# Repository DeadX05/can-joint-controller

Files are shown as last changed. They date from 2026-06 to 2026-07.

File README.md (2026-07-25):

# Distributed Joint Controller over CAN

Two-node ESP32 + CAN-bus system implementing **closed-loop PID position
control of a robotic joint** — a building block toward a quadruped leg.
A target angle typed into the supervisor crosses the bus, the joint
controller drives to it, and status frames stream back.

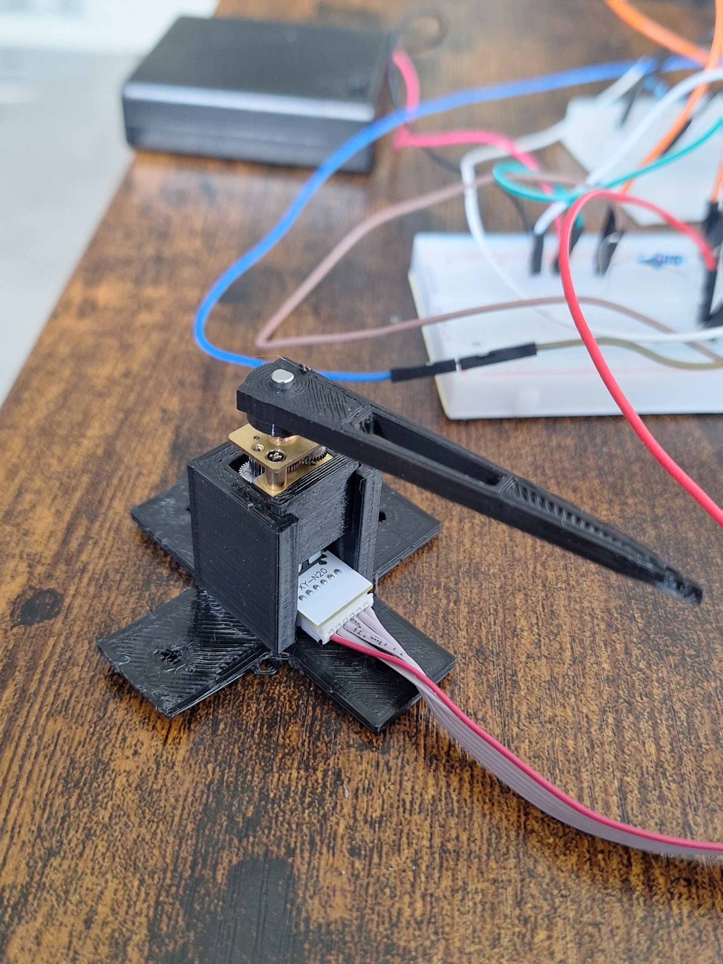
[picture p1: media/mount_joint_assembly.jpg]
Joint assembly


*Joint assembly: N20 gearmotor in the printed mount, front retaining plate
fitted, D-bore lever keyed to the output shaft.*

**[▶ Demo video](media/demo_joint_step_response.mp4)** — a
`0 → 45 → 90 → 0 → −45` step sequence.

**Status: working end to end.** Steady-state error is **0.0–0.5° across
−45°…180°, within the 0.6° control deadband.** The deadband bounds the
error by construction — the controller stops correcting once inside it, and
tightening it reintroduces the stiction limit cycle found during tuning. So
that figure is a design tradeoff, not a performance ceiling.

---

## System overview

- **Node A — joint controller.** ESP32 + TB6612 H-bridge + N20 gearmotor
  with a quadrature encoder. Runs a 100 Hz PID position loop, receives
  `0x100` position commands, publishes `0x110` status at 10 Hz.
- **Node B — supervisor.** ESP32 + MCP2551. Issues targets from serial
  input, consumes telemetry, and doubles as a CSV logging endpoint.
- **Bus.** 250 kbit/s, ESP32 TWAI driver, MCP2551 transceivers.

```
   [ Serial ]                         CAN bus, 250 kbit/s
   PC / user                       (0x100 cmd  →  0x110 status)
       │                        ┌──────────────┬──────────────┐
       ▼                        │              │              │
   ┌─────────┐   0x100 cmd   ┌──┴───┐      ┌───┴────┐    TB6612 → N20 motor
   │ Node B  │ ────────────► │ CAN  │ ◄──► │ Node A │ ──────────────► ))) joint
   │ super-  │ ◄──────────── │ wire │      │ joint  │ ◄── quadrature encoder
   │ visor   │   0x110 status└──────┘      └────────┘
   └─────────┘
```

## Repository structure

```
firmware/
  node_a_joint_controller/   PID position loop + CAN
  node_b_supervisor/         command entry, status display, CSV logging
  tools/                     CAN bring-up sketches + physical-layer self-test
docs/
  protocol.md                CAN message spec (as implemented)
  hardware.md                pinout, physical layer, termination
  engineering-log.md         CAN fault-isolation writeup  ← start here
cad/                         parametric mount/lever generators + STLs
analysis/                    step-response characterisation, plots, logger
media/                       demo video, wiring photos
```

## Hardware

ESP32 ×2, TB6612FNG driver, N20 gearmotor + quadrature encoder, MCP2551 ×2.
Transceivers run at **5 V** with a **220 Ω / 440 Ω divider on each RX line**
back down to ~3.3 V; ~110 Ω termination per node. Full pinout and the
physical-layer reasoning are in [`docs/hardware.md`](docs/hardware.md).

## CAN protocol

| ID | Direction | Payload |
|----|---|---|
| `0x100` | supervisor → joint | `int16` target, 0.1° units |
| `0x110` | joint → supervisor | pos / target / err `int16` (0.1°), effort `uint8`, flags `uint8` (bit0 = settled) |

Full spec: [`docs/protocol.md`](docs/protocol.md).

## Control

100 Hz PID: **Kp = 10, Ki = 0.1, Kd = 0.1**, with a 35-PWM stiction
breakaway, a 0.6° deadband, and an integral anti-windup clamp; range
−45°…180°. Two failure modes were found and fixed during bring-up:

1. **Direction inversion → positive-feedback runaway** — drive direction
   disagreed with the encoder's counting sense; every correction grew the
   error until PWM saturated. Fixed by swapping the H-bridge logic.
2. **Stiction limit cycle** — integral wound up against static friction and
   oscillated. Fixed with friction compensation and a tighter clamp.

## Results

Step response commanded and observed entirely over CAN, across the full
range. Steady-state error stays inside the 0.6° deadband:

| Command | Settled | Error |
|---:|---:|---:|
| 10° | 9.4–10.0° | 0.0–0.5° |
| 20° | 19.7° | 0.2° |
| 45° | 44.6–44.9° | 0.0–0.3° |
| 90° | 89.5–89.8° | 0.1–0.4° |
| 180° | 179.6–180.3° | 0.0–0.3° |
| −45° | −44.9 to −45.2° | 0.0–0.2° |

Full capture, caveats, and the 10 Hz sampling limitation:
[`analysis/step_response_over_can.md`](analysis/step_response_over_can.md).

PID tuning from Day 2 (direct serial, before the bus was integrated):

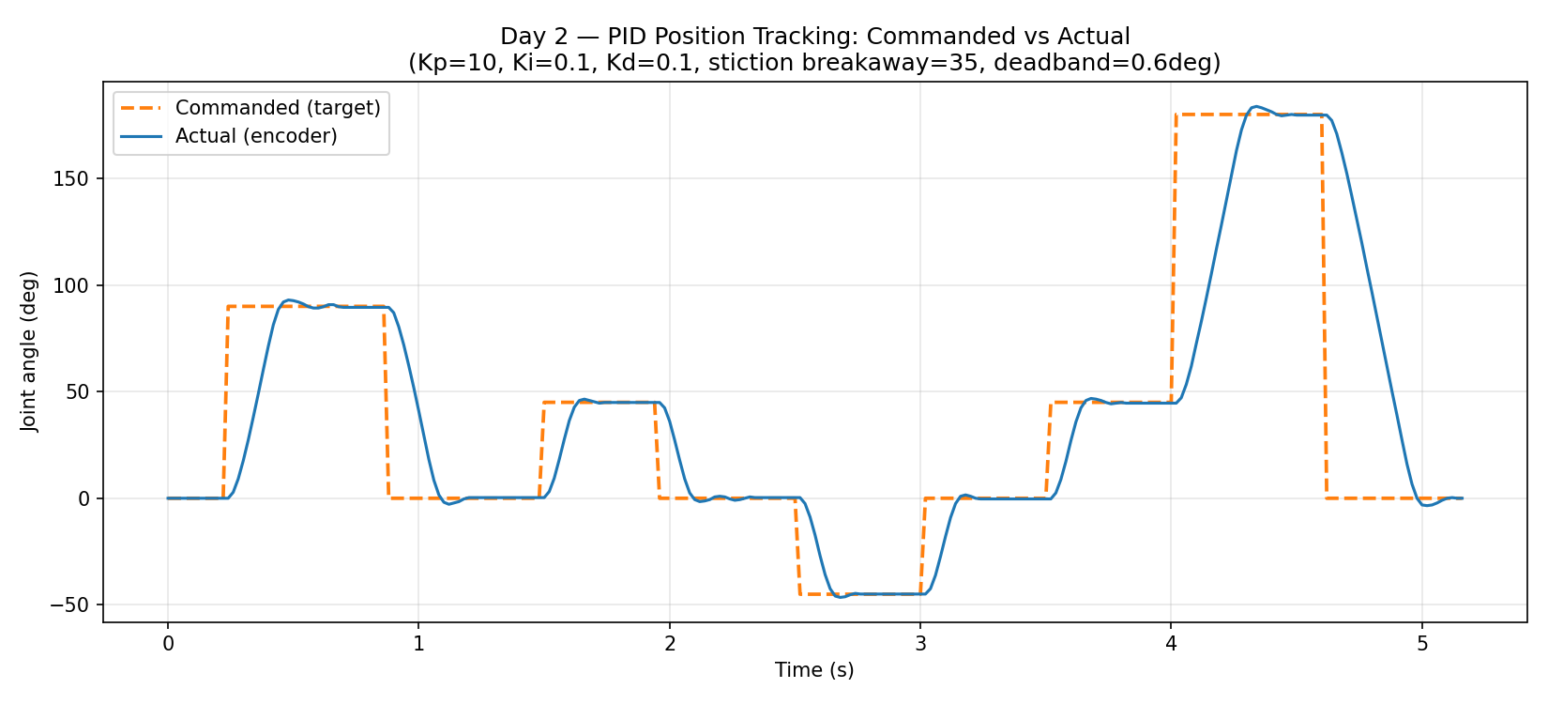
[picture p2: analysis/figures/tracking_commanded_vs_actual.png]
Commanded vs actual

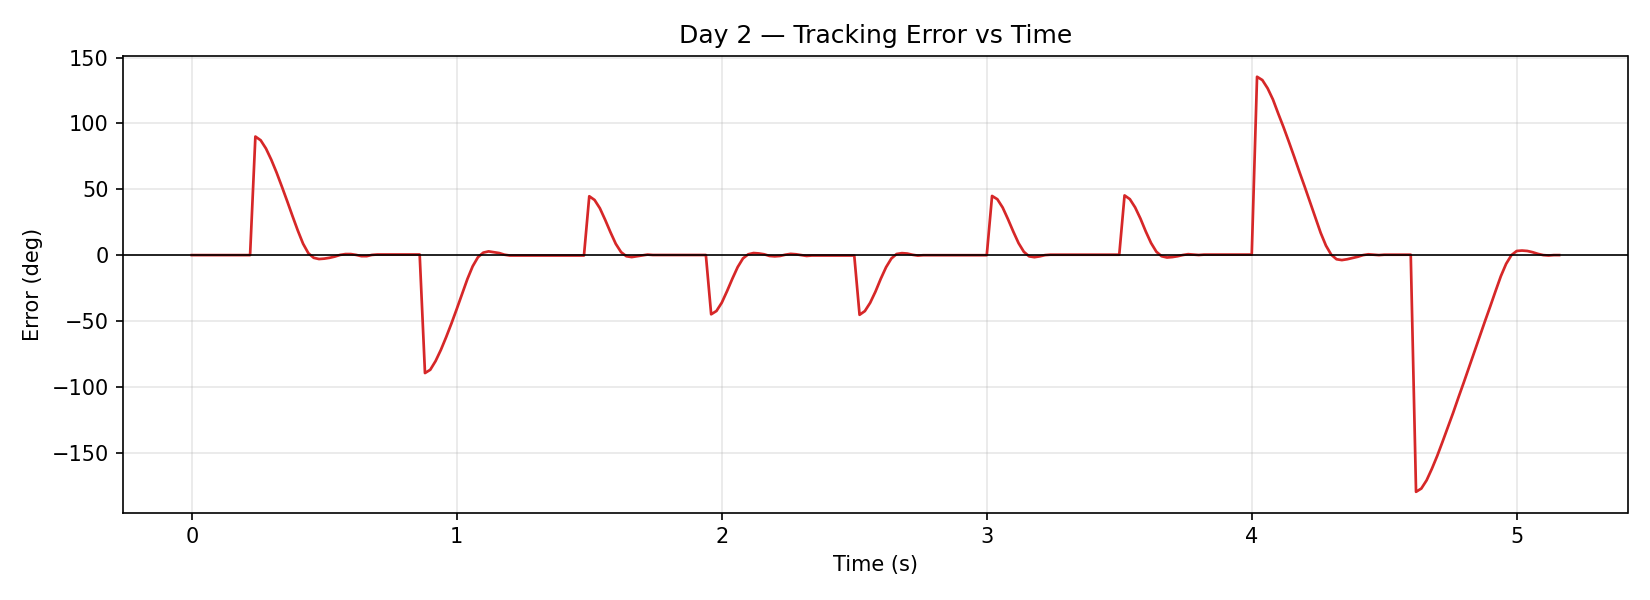
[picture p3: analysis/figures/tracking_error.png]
Tracking error


## Engineering log — the part worth reading

Physical-layer bring-up failed for days; the root cause was **three of five
hand-soldered MCP2551 modules being defective.** It was isolated with a
four-rung diagnostic ladder — status telemetry to make a silent bus
legible, a `TWAI_MODE_NO_ACK` self-test for per-node pass/fail without a
partner, GPIO loopback, and cross-swap — each rung removing one class of
suspect. Verbatim serial captures and bench measurements:
[`docs/engineering-log.md`](docs/engineering-log.md).

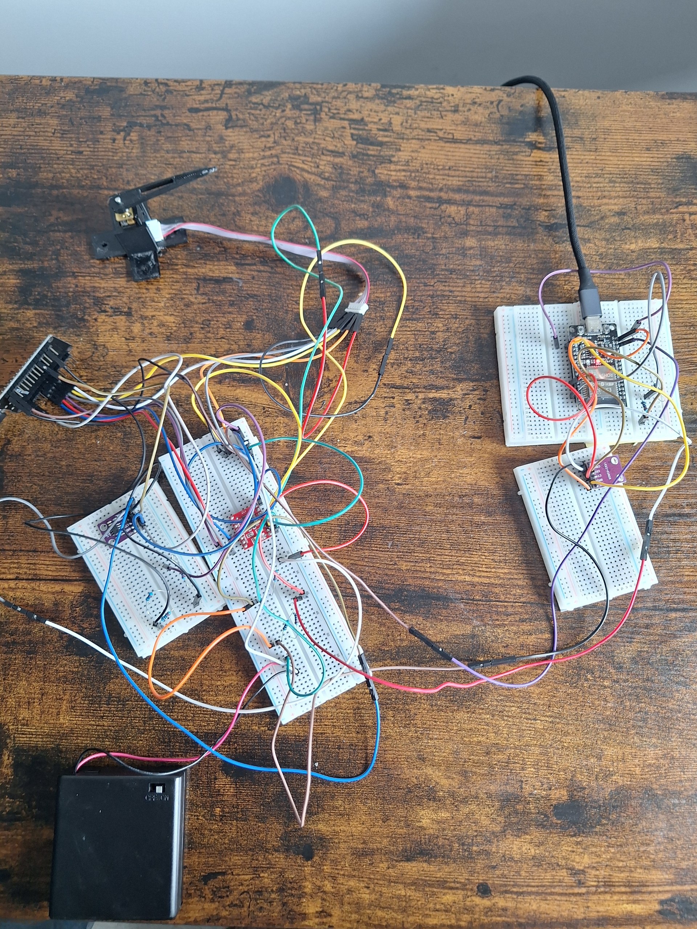
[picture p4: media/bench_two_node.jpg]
Full bench


*Full bench: joint controller node (left, with motor driver and battery)
and supervisor node (right), linked by a three-wire CAN bus.*

## Mechanical

The motor mount is parametric — original in OpenSCAD, later revisions in
Python (`trimesh`) with a named-constant block per part. The design
iterated under physical testing: closed cylindrical pocket that couldn't be
assembled → horizontal test-fit (wrong plane for the tuned PID) → vertical
shaft-up tower (**used for the working demo**) → a rejected closed-front
rev3 → the current **open-front + slide-in retaining plate** (rev4-lite).
The **D-bore lever, keyed to the motor's D-shaft, is printed and fitted**
(the first bore printed undersized in PETG and was opened up — see the
`fix(cad)` history). Generators and STLs in [`cad/`](cad/).

  ## Instructions for demo

  1. Build the hardware as shown in [`docs/hardware.md`](docs/hardware.md).
     Make sure both ESP32 grounds are connected, CANH connects to CANH, CANL
     connects to CANL, and both MCP2551 RXD lines use the documented voltage
     divider.

  2. Flash Node A with:

     `firmware/node_a_joint_controller/node_a_joint_controller.ino`

     Node A should be connected to the TB6612 motor driver, N20 motor, encoder,
     and one MCP2551 transceiver.

  3. Flash Node B with:

     `firmware/node_b_supervisor/node_b_supervisor.ino`

     Node B only needs the second MCP2551 transceiver and USB serial connection
     to the PC.

  4. Open the serial monitor for Node B at **115200 baud** with **newline**
     line ending enabled.

  5. Type target angles into the Node B serial monitor, for example:

     ```text
     45
     90
     180
     0
     -45

  Node B sends each target over CAN as a 0x100 command. Node A runs the
  PID loop and returns 0x110 status frames.

  6. To log CSV telemetry, type:

     L

     Node B will print:

     ms,pos,target,err,pwm,settled

     Type L again to stop logging. The printed rows can be saved as a CSV and
     plotted with the tools in analysis/ (analysis/).

## Known limitations

Kept deliberately visible:

- **Encoder scaling is unverified against a physical measurement.** 1146
  counts/rev was hand-calibrated and the firmware uses it, but no protractor
  check against a commanded angle was done. All reported angles are
  encoder-derived; **absolute angular accuracy is unconfirmed.**
- **Overshoot on fast steps.** Large moves travel past target and recover:
  89.5°→0 reached −1.5°, 180°→0 reached +1.2°, 0°→−45° reached −47.4° and
  −46.1° on two runs — every recovery at `pwm=35`, the stiction floor. Cause:
  the printed lever's rotational inertia back-driving the joint, with nothing
  damping it because the TB6612 is left in coast (both inputs LOW) rather
  than short brake at zero command. *Roadmap: brake instead of coast on stop.*
- **Telemetry sampling artifact.** Status frames report drive effort from
  the previous control iteration while position and error are sampled at
  send time, so the two disagree for one frame after a target change —
  visible as `err=9.9 pwm=0` in the logs. Documented in `sendStatus()`.
- **No fail-safe.** No heartbeat, command timeout, or watchdog — if the bus
  drops, the joint holds its last target forever.
- **Thin 5 V headroom.** One node's rail sits at 4.6 V (spec min 4.5 V);
  divider midpoints ~2.7 V vs a ~2.5 V threshold. A 3.3 V-native transceiver
  (SN65HVD230, TJA1051T/3) would remove the dividers and the concern.
- **Single joint; unloaded.** Multi-node bus arbitration is untested, and
  step responses carry no external load or disturbance-rejection data.

## Authors

- **Izzatbek Murodjonov ([@inteeed](https://github.com/inteeed))** —
  hardware design, physical-layer bring-up & fault isolation, PID tuning,
  mechanical design
- **Boburjon Radjapov ([@DeadX05](https://github.com/DeadX05))** — CAN
  protocol design, supervisor firmware, integration testing

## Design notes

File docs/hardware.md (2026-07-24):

# Hardware

Two-node CAN system: **Node A** (joint controller) and **Node B**
(supervisor), each an ESP32 paired with an MCP2551 CAN transceiver on a
shared 250 kbit/s bus driven by the ESP32 TWAI peripheral.

> This document reflects the **working configuration**. The CAN physical
> layer went through a 3.3 V → 5 V revision during bring-up; see
> `engineering-log.md` for that investigation.

## CAN bus / physical layer

| Signal | Connection |
|---|---|
| MCP2551 CTX (TXD) | ESP32 GPIO21 — direct (3.3 V is a valid logic high in) |
| MCP2551 CRX (RXD) | ESP32 GPIO22 — through a 220 Ω / 440 Ω divider |
| MCP2551 VCC | 5 V (ESP32 VIN) |
| MCP2551 GND | common ground |
| Bitrate | 250 kbit/s (ESP32 TWAI) |

The MCP2551 is specified for a 4.5–5.5 V supply, so the transceivers run
at **5 V**, not 3.3 V. (An earlier 3.3 V configuration was out of spec and
a suspected source of silent frame loss during bring-up — see
`engineering-log.md`.) Because RXD then swings to 5 V, each RX line uses a
**220 Ω / 440 Ω divider** stepping it down to ~3.3 V at the ESP32 input.
TXD needs nothing: 3.3 V is already a valid logic high into the
transceiver.

Measured after the migration: Node A VCC **5.0 V**, Node B VCC **4.6 V**
(in spec but little headroom), RX divider midpoints **~2.7–3.0 V** (above
the ESP32 logic-high threshold, but thin — a 3.3 V-native transceiver such
as the SN65HVD230 or TJA1051T/3 would remove both the dividers and the
headroom concern).

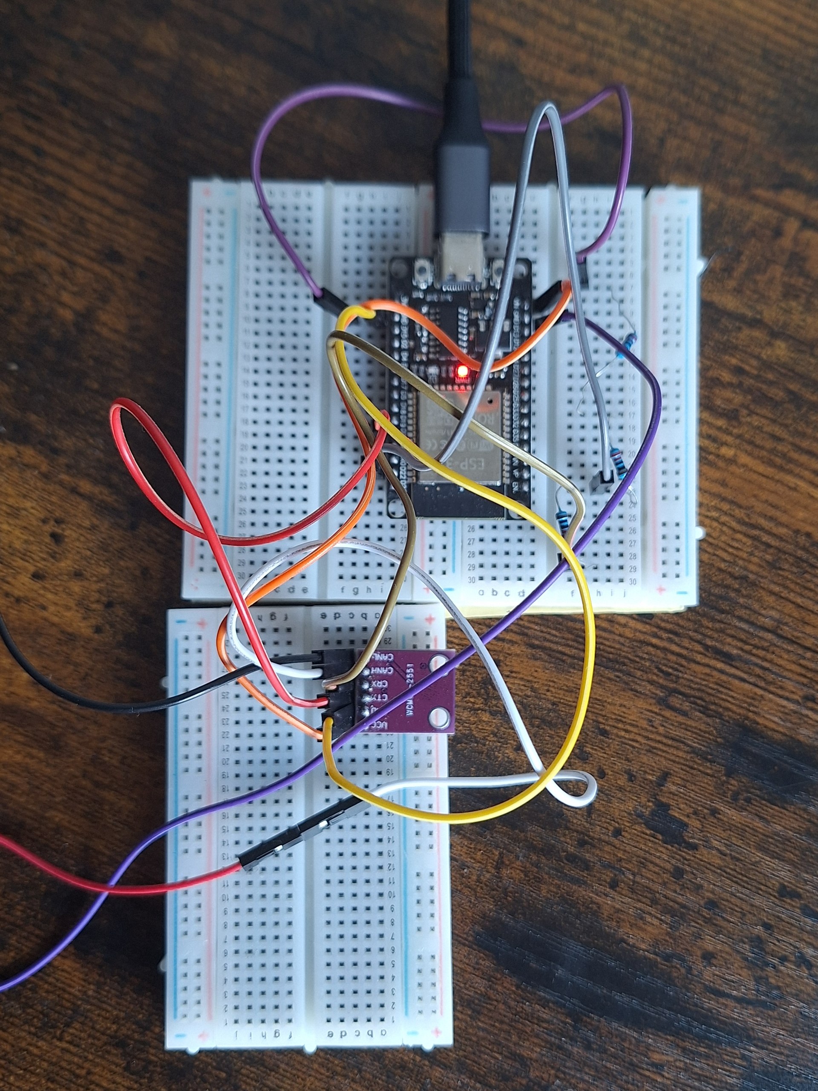
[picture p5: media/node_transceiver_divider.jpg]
Node B transceiver and RX divider


*Node B transceiver and the 220 Ω/440 Ω divider stepping the 5 V RXD output
down to ~3.3 V for the ESP32 input.*

### Bus topology & termination
- CANH ↔ CANH, CANL ↔ CANL, GND ↔ GND between nodes.
- Termination: 2 × 220 Ω in parallel at each node (~110 Ω per node),
  giving **~55 Ω measured across the bus**.

## Node A — motor & encoder

### TB6612 H-bridge
| Signal | Pin |
|---|---|
| AIN1 | GPIO26 |
| AIN2 | GPIO27 |
| PWMA | GPIO25 |
| STBY | GPIO14 (driven HIGH — motor is disabled if LOW) |
| VCC (logic) | 3.3 V |
| VM (motor) | battery + |
| GND | common ground (battery −) |

### Quadrature encoder
| Signal | Pin |
|---|---|
| Ch A | GPIO32 |
| Ch B | GPIO33 |
| Vcc | 3.3 V |
| GND | common ground |

**Counts per rev:** 1146, hand-calibrated — the nominal 7 PPR × 100:1 = 700
figure was wrong on this unit, and the firmware uses 1146. It was derived
from encoder counts, **not** checked against an independent physical angle
measurement, so absolute angular accuracy is unconfirmed (see the README's
known limitations).

## Node B — supervisor

ESP32 + MCP2551 only, CAN wiring as above. No motor hardware — it issues
position-command frames, consumes status frames off the bus, and logs to
the PC over USB serial.

## Pin summary

| Node | Function | Pin |
|---|---|---|
| Both | CAN CTX / CRX | GPIO21 / GPIO22 |
| A | TB6612 AIN1 / AIN2 / PWMA | GPIO26 / GPIO27 / GPIO25 |
| A | TB6612 STBY | GPIO14 |
| A | Encoder Ch A / Ch B | GPIO32 / GPIO33 |

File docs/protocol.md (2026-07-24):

# CAN Bus Protocol Specification

**Project:** Distributed Joint Controller over CAN
**Bus baud rate:** 250 kbit/s
**Termination:** ~110 Ω per node (2 × 220 Ω in parallel), ~55 Ω across the bus
**Frame format:** Standard 11-bit CAN ID, data frame

> The original Day-1 design used 4-byte IEEE-754 floats. The implementation
> switched to **int16 fixed-point in units of 0.1°** — half the payload,
> no endianness/float portability concerns, and ample resolution for a
> position loop. This document describes the protocol as implemented.

---

## Message Table

| ID | Name | Direction | Length  | Rate |
|---|---|---|---|---|
| 0x100 | position_cmd | Supervisor → Joint | 2 bytes | on command |
| 0x110 | joint_status | Joint → Supervisor | 8 bytes | 10 Hz |

All multi-byte fields are **little-endian**, signed unless noted.

---

## 0x100 — position_cmd

Sent by Node B (supervisor) to Node A (joint controller) when a target is
entered. Commands the PID setpoint.

```
Byte 0-1:  int16  target_deg_x10   (degrees × 10; 900 = 90.0°)
```

Clamped to the joint's −45°…180° range **at the receiver**.

**Example:** command 90.0° → `900` → bytes `84 03`.

---

## 0x110 — joint_status

Sent by Node A to Node B at 10 Hz. Carries everything the supervisor needs
to display, log, and detect settling.

```
Byte 0-1:  int16   position_deg_x10   (degrees × 10)
Byte 2-3:  int16   target_deg_x10     (degrees × 10)
Byte 4-5:  int16   error_deg_x10      (degrees × 10)
Byte 6:    uint8   effort             (abs PWM duty, 0-255)
Byte 7:    uint8   flags              (bit0 = settled, within deadband)
```

**Example:** position 87.3°, target 90.0°, error 2.7°, PWM 40, not settled
→ `69 03  84 03  1B 00  28  00`.

---

## Encoding / decoding (C)

```c
// Pack a degree value into an int16 field (0.1° units)
int16_t v = (int16_t)(deg * 10);
data[0] = v & 0xFF;
data[1] = v >> 8;

// Unpack
int16_t v = (int16_t)(data[0] | (data[1] << 8));
float deg = v / 10.0f;
```

---

## Node IDs / roles

| Node | Role | Sends | Receives |
|---|---|---|---|
| Node A | Joint ctrl | 0x110 | 0x100 |
| Node B | Supervisor | 0x100 | 0x110 |

---

## Error / debug notes

- No frames received: check shared GND between nodes, matching 250 kbit/s
  bitrate, and that termination is present at both nodes.
- CANH/CANL must not be swapped.
- The MCP2551 is run at **5 V** (it is spec'd for 4.5–5.5 V); each ESP32 RX
  line uses a 220 Ω / 440 Ω divider to bring the 5 V RXD down to ~3.3 V.
  See `hardware.md` and `engineering-log.md` for why.

---

## Future extension (planned, not implemented)

Scaling to a multi-DOF leg would add per-joint IDs, e.g. `0x101`/`0x111`
for a second joint and `0x120` for a foot IMU. Multi-node bus arbitration
is untested — see the README's known limitations.

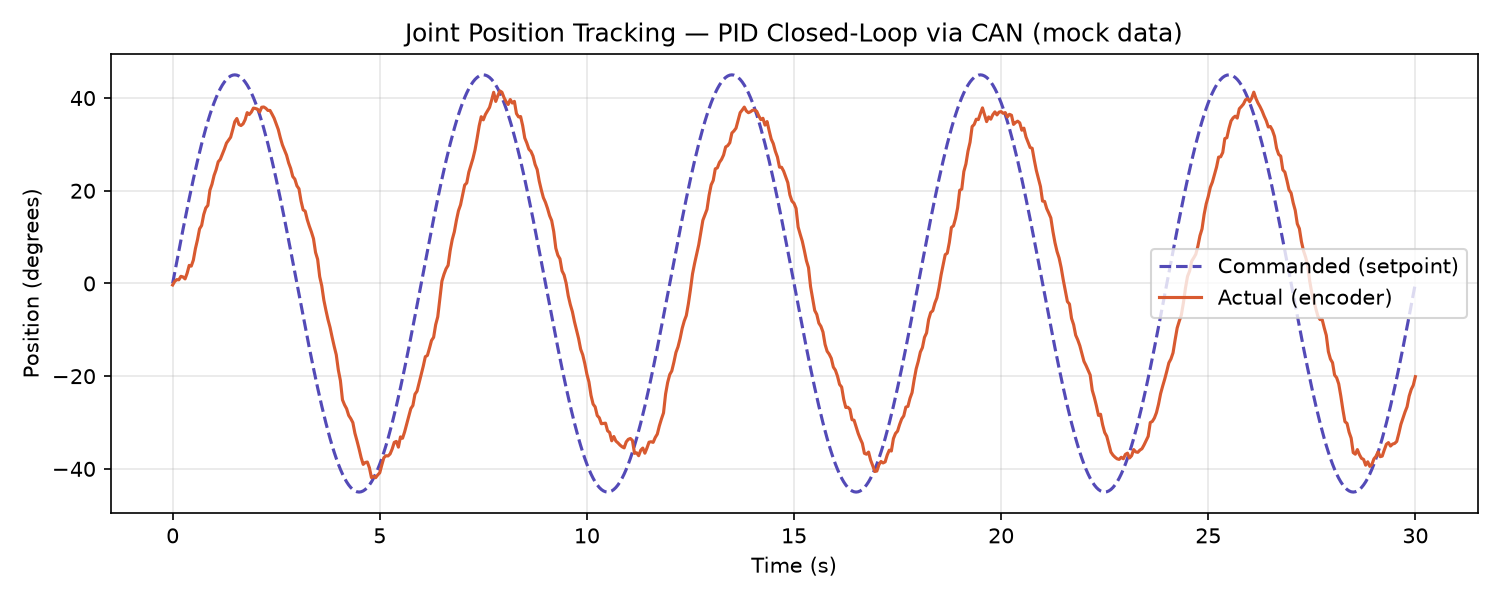
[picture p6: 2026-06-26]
analysis/figures/tracking_(mock_data).png

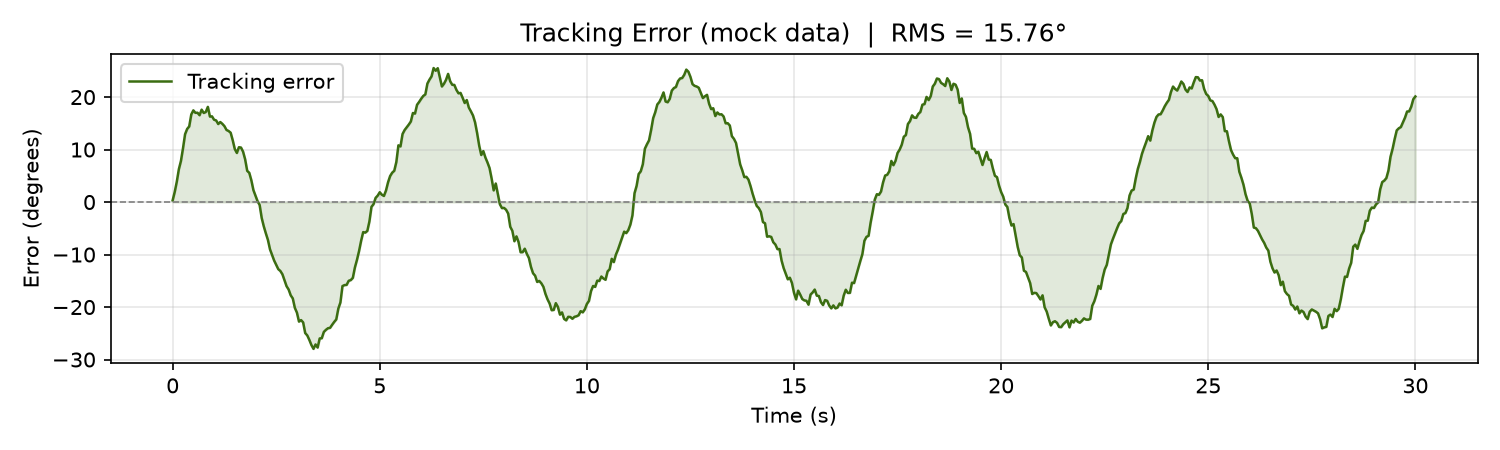
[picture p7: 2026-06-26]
analysis/figures/error_(mock_data).png

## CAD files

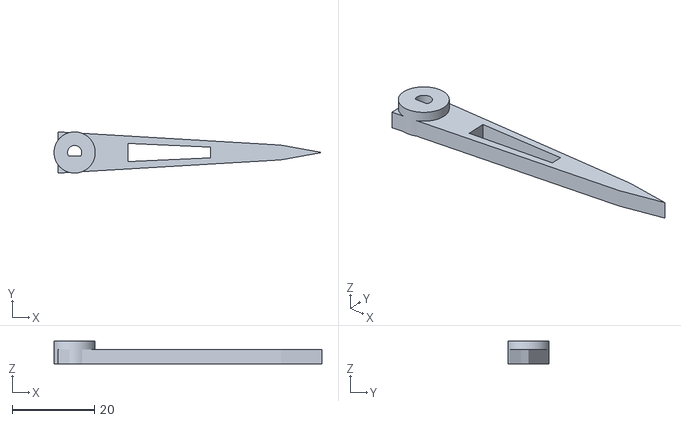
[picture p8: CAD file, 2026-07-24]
cad/lever_arm_demo_v2.stl
65.0 x 10.0 x 5.50

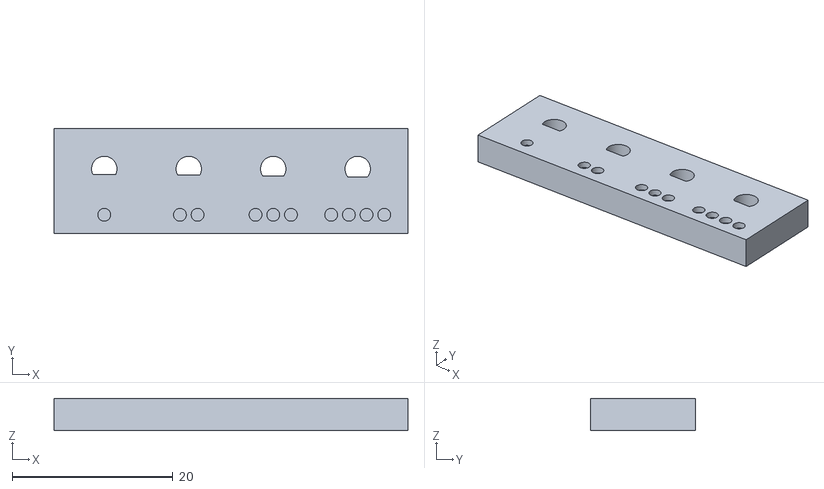
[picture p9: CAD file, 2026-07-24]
cad/d_shaft_fit_coupon_small.stl
44.0 x 13.0 x 4.00

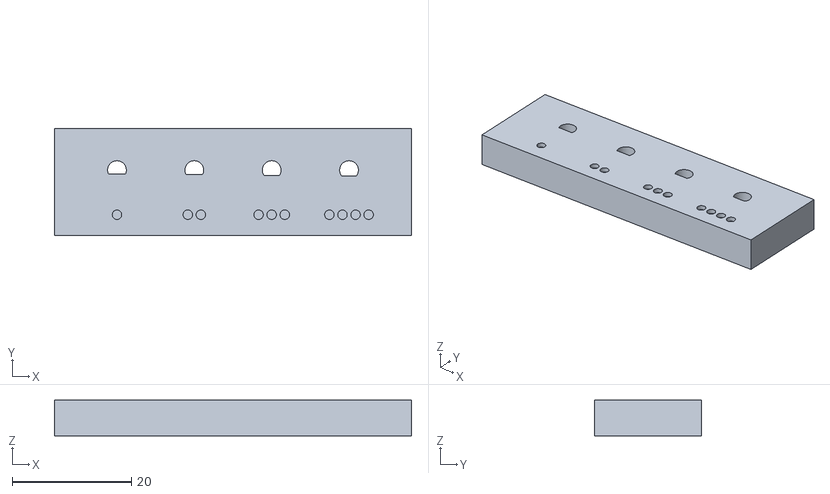
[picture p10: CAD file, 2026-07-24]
cad/d_shaft_fit_coupon.stl
60.0 x 18.0 x 6.00

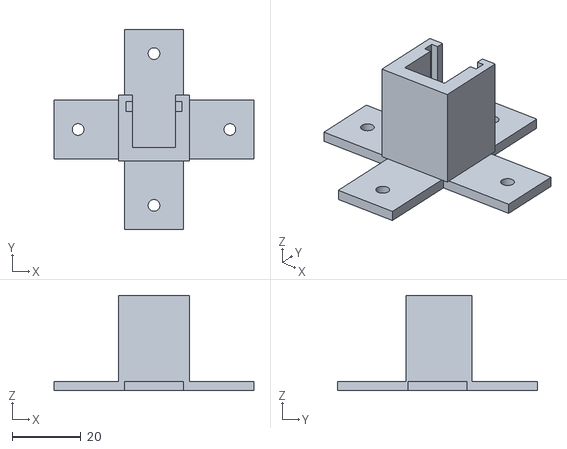
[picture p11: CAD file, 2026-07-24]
cad/n20_mount_rev4_lite.stl
58.0 x 58.0 x 27.6

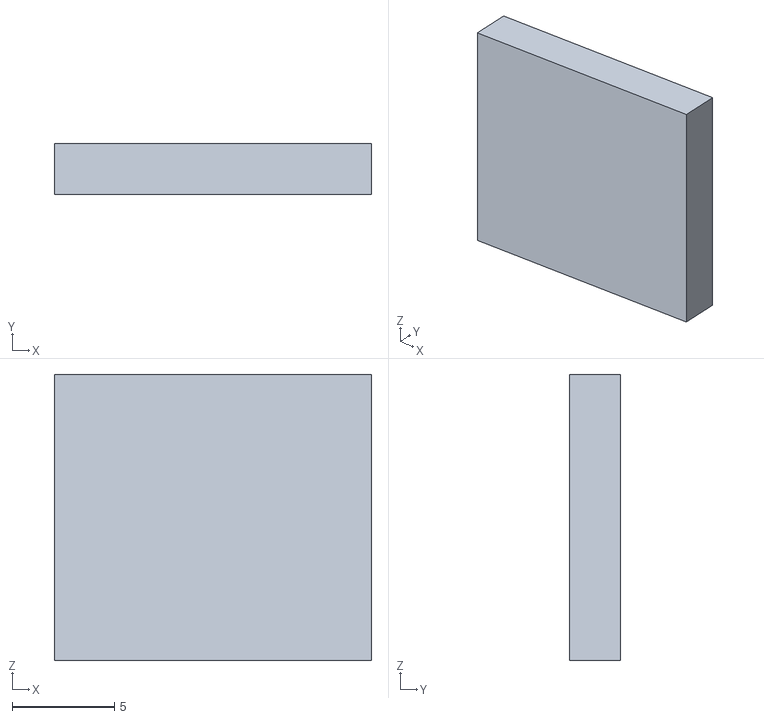
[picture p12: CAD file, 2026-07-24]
cad/n20_front_plate_lite.stl
15.5 x 2.50 x 14.0

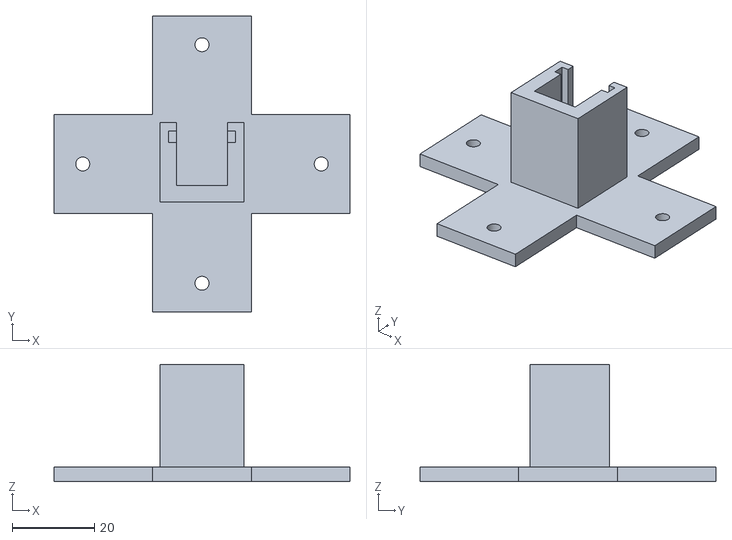
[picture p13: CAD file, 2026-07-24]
cad/n20_mount_rev4.stl
72.0 x 72.0 x 28.5

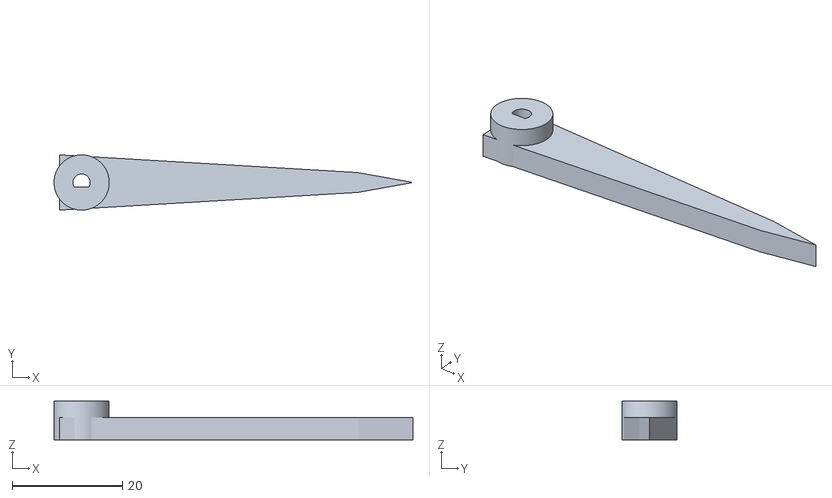
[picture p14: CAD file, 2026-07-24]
cad/lever_arm.stl
65.0 x 10.0 x 7.00

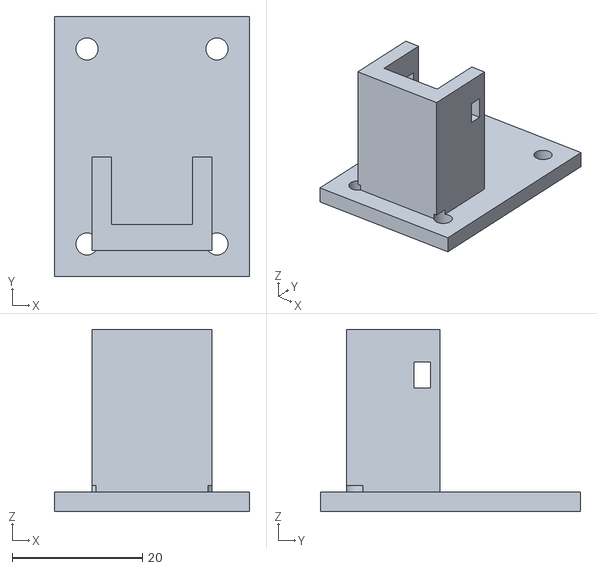
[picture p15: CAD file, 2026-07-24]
cad/n20_vertical_mount.stl
30.0 x 40.0 x 28.0

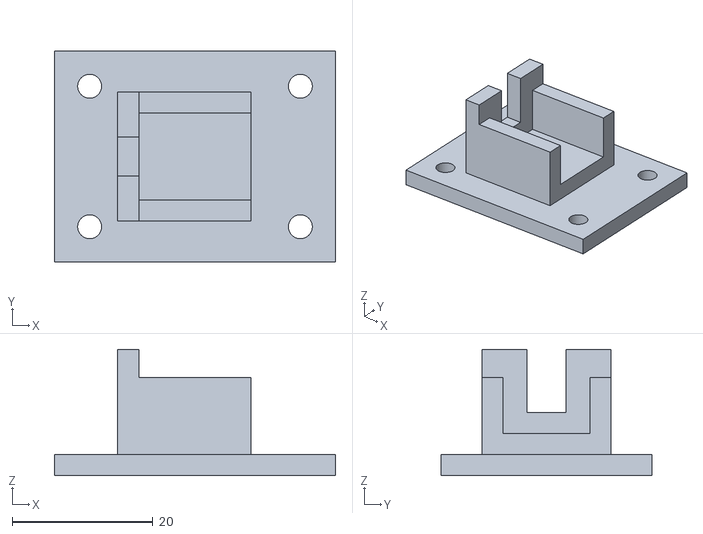
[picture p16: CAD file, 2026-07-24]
cad/n20_mount_test_fit.stl
40.0 x 30.0 x 18.0

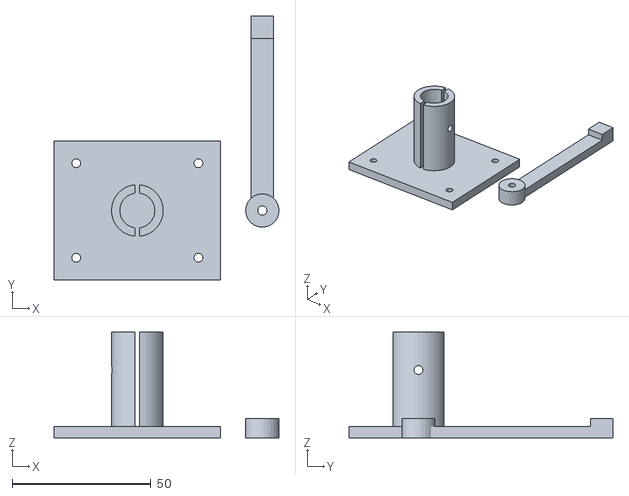
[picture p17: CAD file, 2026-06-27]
cad/motor_bracket.stl
81.0 x 95.0 x 38.0

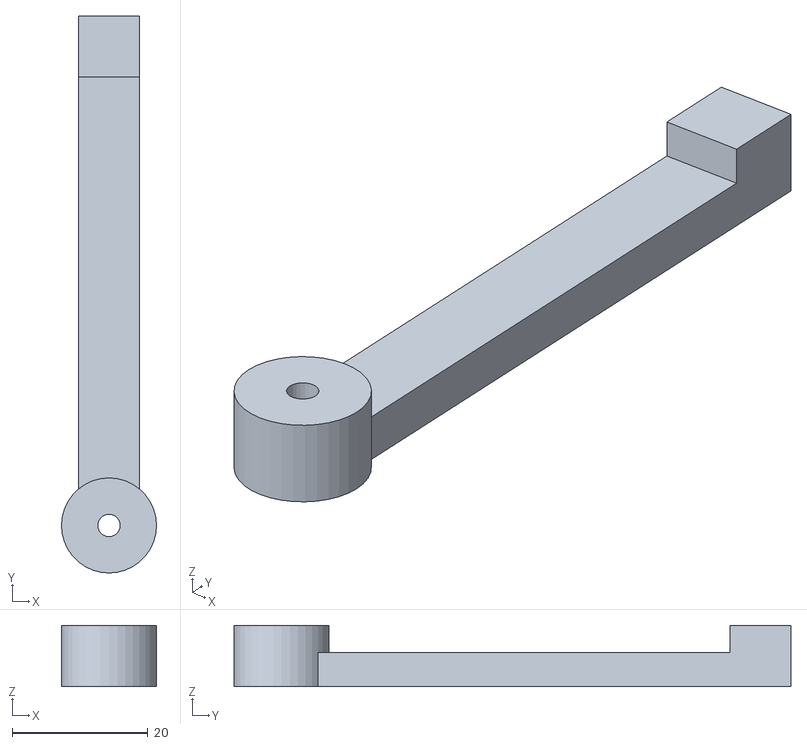
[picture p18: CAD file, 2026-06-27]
cad/motor_bracket_lever.stl
14.0 x 82.0 x 9.00

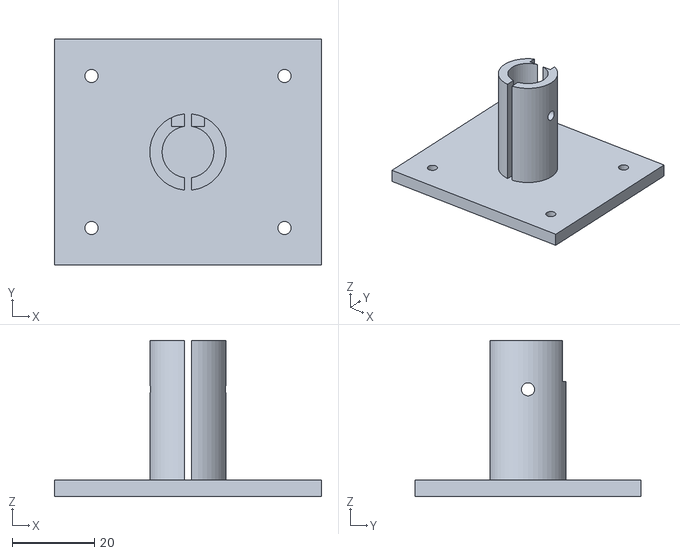
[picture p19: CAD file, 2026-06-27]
cad/motor_bracket_body.stl
65.0 x 55.0 x 38.0

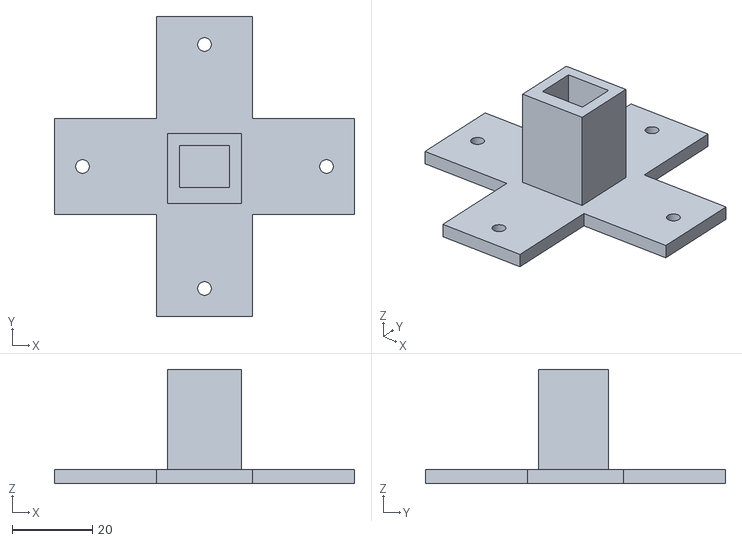
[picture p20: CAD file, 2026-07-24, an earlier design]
cad/n20_mount_rev3.stl
75.0 x 75.0 x 28.5

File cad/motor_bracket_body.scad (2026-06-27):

// ============================================================
//  N20 Motor Mount Bracket — BODY ONLY
//  Print this file as one STL.
//
//  Dimensions from Waveshare N20 DC Gear Motor datasheet:
//    Motor body diameter : 12mm
//    Motor body length   : 24mm
//    Encoder length      : 10mm
//    Shaft diameter      : 3mm
//
//  Print settings: 0.2mm layer, 40% infill, PETG or PLA
//  No supports needed.
// ============================================================

motor_diameter  = 12.0;
motor_length    = 24.0;
encoder_length  = 10.0;
clamp_wall      = 3.0;
base_thickness  = 4.0;
base_width      = 55.0;
base_length     = 65.0;
m3_hole         = 3.2;
tolerance       = 0.3;

motor_r       = motor_diameter / 2 + tolerance;
clamp_outer_r = motor_r + clamp_wall;
clamp_height  = motor_length + encoder_length;  // 34mm total
clamp_x       = base_length / 2;
clamp_y       = base_width / 2;

// Cable slot dimensions — for encoder ribbon cable exit
cable_slot_w  = 8.0;   // wide enough for 6-wire ribbon
cable_slot_d  = 3.0;   // depth into collar wall

difference() {
    union() {
        // ── Base plate ────────────────────────────────────
        cube([base_length, base_width, base_thickness]);

        // ── Motor clamp collar ────────────────────────────
        translate([clamp_x, clamp_y, base_thickness])
            cylinder(h = clamp_height, r = clamp_outer_r, $fn = 48);
    }

    // M3 corner mounting holes
    for (x = [9, base_length - 9])
        for (y = [9, base_width - 9])
            translate([x, y, -0.1])
                cylinder(h = base_thickness + 0.2, r = m3_hole / 2, $fn = 20);

    // Inner bore for motor body (full height)
    translate([clamp_x, clamp_y, base_thickness - 0.1])
        cylinder(h = clamp_height + 0.2, r = motor_r, $fn = 48);

    // Clamp gap slot — one side, allows collar to flex with M3 screw
    translate([clamp_x - 0.9, clamp_y - clamp_outer_r - 0.1, base_thickness - 0.1])
        cube([1.8, clamp_outer_r * 2 + 0.2, clamp_height + 0.2]);

    // M3 clamp screw hole — horizontal through collar walls
    translate([clamp_x - clamp_outer_r - 0.1, clamp_y, base_thickness + clamp_height * 0.65])
        rotate([0, 90, 0])
            cylinder(h = clamp_outer_r * 2 + 0.2, r = m3_hole / 2, $fn = 20);

    // Cable routing slot — at encoder end (top of collar)
    // Encoder ribbon exits here cleanly instead of bending around the collar
    translate([clamp_x - cable_slot_w / 2,
               clamp_y + motor_r - 0.1,
               base_thickness + motor_length])
        cube([cable_slot_w, cable_slot_d + 0.1, encoder_length + 0.2]);
}

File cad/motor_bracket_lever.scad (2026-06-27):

// ============================================================
//  N20 Motor Lever Arm — SEPARATE PRINT
//  Print this file flat on the build plate.
//
//  Attaches to the 3mm output shaft of the N20 motor.
//  The tip bump makes the arm clearly visible in demo video.
//
//  Print settings: 0.2mm layer, 40% infill, PETG or PLA
// ============================================================

shaft_diameter  = 3.0;
tolerance       = 0.3;
lever_length    = 75.0;   // tip to shaft center
lever_width     = 9.0;
lever_thickness = 5.0;
hub_r           = lever_width / 2 + 2.5;

difference() {
    union() {
        // Main arm
        translate([-lever_width / 2, 0, 0])
            cube([lever_width, lever_length, lever_thickness]);

        // Hub reinforcement around shaft
        cylinder(h = lever_thickness + 4, r = hub_r, $fn = 36);

        // Tip bump — visually distinct end for demo video
        translate([-lever_width / 2, lever_length - lever_width, 0])
            cube([lever_width, lever_width, lever_thickness + 4]);
    }

    // Shaft press-fit hole
    translate([0, 0, -0.1])
        cylinder(h = lever_thickness + 4.2, r = (shaft_diameter + tolerance) / 2, $fn = 24);

    // M2 set-screw hole through hub side (optional — for extra grip on shaft)
    translate([hub_r + 0.1, 0, (lever_thickness + 4) / 2])
        rotate([0, 90, 0])
            cylinder(h = hub_r * 2 + 0.2, r = 1.1, $fn = 16);
}

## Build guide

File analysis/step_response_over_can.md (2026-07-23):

# Step-Response Characterisation over CAN

Closed-loop step response of the joint, commanded and observed entirely
over the CAN bus. Below: the raw supervisor (Node B) serial output during
commanded step sequences — the joint controller (Node A) running the tuned
PID and returning 0x110 status frames — followed by the settled-error and
overshoot summaries.

## Provenance — read this before using the numbers

This file is **transcribed from serial-monitor screenshots**, not saved
from the original serial buffer. The buffer was lost when the monitor was
closed. Consequences:

- Only the portions visible on screen are reproduced. There are **gaps
  between runs and between scroll positions** — these are marked.
- Long stretches of identical `[SETTLED]` lines are **collapsed** with an
  annotation. The exact repeat counts are not recoverable, so no count is
  asserted.
- Every value below is read directly off a screenshot. Values are believed
  accurate; absence of a line is not evidence it did not occur.

The original screenshots are the primary evidence and should be kept
alongside this file.

Status frames were emitted at 10 Hz (100 ms) in these runs. The non-logging
display path throttles printing to one line per 500 ms, so **transients
between status prints are not resolved**. Peak overshoot values below are
whatever happened to be sampled, and true peaks may be larger.

---

## Run 1

```
# logging off
STATUS: pos=0.3  target=0.0  err=-0.3  pwm=0  [SETTLED]
    [line repeats]
# command sent: 10.0
STATUS: pos=9.4  target=10.0  err=0.5  pwm=0  [SETTLED]
    [line repeats]
# command sent: 45.0
STATUS: pos=20.1  target=45.0  err=24.8  pwm=245
STATUS: pos=44.6  target=45.0  err=0.3  pwm=0  [SETTLED]
    [line repeats]
# command sent: 90.0
STATUS: pos=89.5  target=90.0  err=0.4  pwm=0  [SETTLED]
    [line repeats]

    [scroll gap]

# command sent: 180.0
STATUS: pos=158.0  target=180.0  err=21.9  pwm=217
STATUS: pos=180.0  target=180.0  err=0.0  pwm=0  [SETTLED]
    [line repeats]
# command sent: 0.0
STATUS: pos=161.1  target=0.0  err=-161.1  pwm=255
STATUS: pos=0.9  target=0.0  err=-0.9  pwm=35
STATUS: pos=0.0  target=0.0  err=0.0  pwm=0  [SETTLED]
    [line repeats]
# command sent: -45.0
STATUS: pos=-46.4  target=-45.0  err=1.4  pwm=35
STATUS: pos=-45.2  target=-45.0  err=0.2  pwm=0  [SETTLED]
    [line repeats]
# command sent: 0.0
STATUS: pos=0.0  target=0.0  err=0.0  pwm=0  [SETTLED]
    [line repeats]
```

Logging was then enabled while the joint was already parked, so the CSV
rows from this run contain only the stationary state:

```
ms,pos,target,err,pwm,settled
162962,0.0,0.0,0.0,0,1
162982,0.0,0.0,0.0,0,1
    [identical rows continue to at least 165002]
```

---

## Run 2

```
STATUS: pos=0.0  target=0.0  err=0.0  pwm=0  [SETTLED]
    [line repeats]
# command sent: 0.0
STATUS: pos=0.0  target=0.0  err=0.0  pwm=0  [SETTLED]
    [line repeats]
# command sent: 10.0
STATUS: pos=10.0  target=10.0  err=0.0  pwm=0  [SETTLED]
    [line repeats]
# command sent: 20.0
STATUS: pos=10.0  target=20.0  err=9.9  pwm=0
STATUS: pos=19.7  target=20.0  err=0.2  pwm=0  [SETTLED]
    [line repeats]
# command sent: 45.0
STATUS: pos=44.9  target=45.0  err=0.0  pwm=0  [SETTLED]
    [line repeats]
# command sent: 90.0
STATUS: pos=63.4  target=90.0  err=26.5  pwm=255
STATUS: pos=89.5  target=90.0  err=0.4  pwm=0  [SETTLED]
    [line repeats]
# command sent: 0.0
STATUS: pos=-1.5  target=0.0  err=1.5  pwm=35
STATUS: pos=-0.3  target=0.0  err=0.3  pwm=0  [SETTLED]
    [line repeats]
# command sent: 180.0
STATUS: pos=37.6  target=180.0  err=142.3  pwm=255
STATUS: pos=180.3  target=180.0  err=-0.3  pwm=0  [SETTLED]
    [line repeats]
# command sent: 0.0
STATUS: pos=156.4  target=0.0  err=-156.4  pwm=255
STATUS: pos=1.2  target=0.0  err=-1.2  pwm=35
STATUS: pos=0.0  target=0.0  err=0.0  pwm=0  [SETTLED]
    [line repeats]
# command sent: -45.0
STATUS: pos=-47.4  target=-45.0  err=2.4  pwm=35
STATUS: pos=-45.2  target=-45.0  err=0.2  pwm=0  [SETTLED]
    [line repeats]
# command sent: 0.0
STATUS: pos=-41.1  target=0.0  err=41.1  pwm=255
STATUS: pos=0.3  target=0.0  err=-0.3  pwm=0  [SETTLED]
    [line repeats]
```

Logging enabled after the sequence completed; again only the parked state
was recorded:

```
ms,pos,target,err,pwm,settled
891925,0.3,0.0,-0.3,0,1
891945,0.3,0.0,-0.3,0,1
    [identical rows continue]
```

---

## Run 3 (partial — earlier portion not captured)

```
STATUS: pos=89.8  target=90.0  err=0.1  pwm=0  [SETTLED]
    [line repeats]
# command sent: 180.0
STATUS: pos=179.6  target=180.0  err=0.3  pwm=35  [SETTLED]
STATUS: pos=179.6  target=180.0  err=0.3  pwm=0   [SETTLED]
    [line repeats]
# command sent: 0.0
STATUS: pos=41.7  target=0.0  err=-41.7  pwm=255
STATUS: pos=0.0  target=0.0  err=0.0  pwm=0  [SETTLED]
    [line repeats]
# command sent: -45.0
STATUS: pos=-46.1  target=-45.0  err=1.1  pwm=35
STATUS: pos=-44.9  target=-45.0  err=0.0  pwm=0  [SETTLED]
    [line repeats]
# command sent: 0.0
STATUS: pos=0.6  target=0.0  err=-0.6  pwm=35
STATUS: pos=-0.3  target=0.0  err=0.3  pwm=0  [SETTLED]
    [line repeats]
```

Logging enabled at the end, joint parked:

```
ms,pos,target,err,pwm,settled
36220,-0.3,0.0,0.3,0,1
36240,-0.3,0.0,0.3,0,1
    [identical rows continue to at least 36400]
```

Note the 20 ms timestamp spacing here: this run used the 50 Hz
characterisation build of the joint controller. The committed default is
100 ms (10 Hz).

---

## Reading artifact — `pwm` lags by one control cycle

Several lines show an inconsistent-looking `pwm` value, e.g.

```
STATUS: pos=10.0  target=20.0  err=9.9  pwm=0
STATUS: pos=179.6 target=180.0 err=0.3  pwm=35  [SETTLED]
```

This is not a control fault. `sendStatus()` reports `lastPwm`, which is
written by the previous PID iteration. When a status frame is emitted
between a target change and the next control tick, it carries the drive
value from before the change. The `settled` flag, by contrast, is computed
fresh at send time. The two can therefore disagree for one frame.

---

## Summary — settled position by commanded angle

| Command | Settled position(s) | Error |
|---|---|---|
| 10 | 9.4, 10.0 | 0.5, 0.0 |
| 20 | 19.7 | 0.2 |
| 45 | 44.6, 44.9 | 0.3, 0.0 |
| 90 | 89.5, 89.5, 89.8 | 0.4, 0.4, 0.1 |
| 180 | 180.0, 180.3, 179.6 | 0.0, 0.3, 0.3 |
| −45 | −45.2, −45.2, −44.9 | 0.2, 0.2, 0.0 |
| 0 | 0.0, −0.3, 0.3 | 0.0, 0.3, 0.3 |

Steady-state error across all runs: **0.0–0.5°**, every value inside the
0.6° control deadband. The deadband is what bounds this figure — the
controller stops correcting once within it — so the number reflects a
design parameter, not a measurement limit. Tightening the deadband
reintroduces the stiction-driven limit cycle identified during PID tuning.

## Summary — overshoot on large steps

| Transition | Sampled peak | Excursion past target | Recovered to |
|---|---|---|---|
| 89.5 → 0 | −1.5 | 1.5° | −0.3 |
| 180 → 0 | +1.2 | 1.2° | 0.0 |
| 0 → −45 | −47.4 | 2.4° | −45.2 |
| 0 → −45 | −46.1 | 1.1° | −44.9 |
| 0.9 → 0 | +0.9 | 0.9° | 0.0 |

Large, fast moves travel past the target and are pulled back. Every
recovery line reads `pwm=35`, the stiction breakaway floor — the smallest
drive the controller will apply — so the joint is being walked back into
the deadband at minimum effort.

Attributed to the rotational inertia of the printed lever back-driving the
joint after the controller cuts drive. The TB6612 is left with both
direction inputs LOW at zero command, which is high-impedance coast rather
than short brake, so nothing damps that momentum. Switching the zero case
to short brake (both inputs HIGH) is the candidate mitigation and is not
yet tested.

Peaks above are the values that happened to fall on a status frame. With
500 ms display throttling in these runs, true peak overshoot may be larger
and the recovery transient is not resolved.

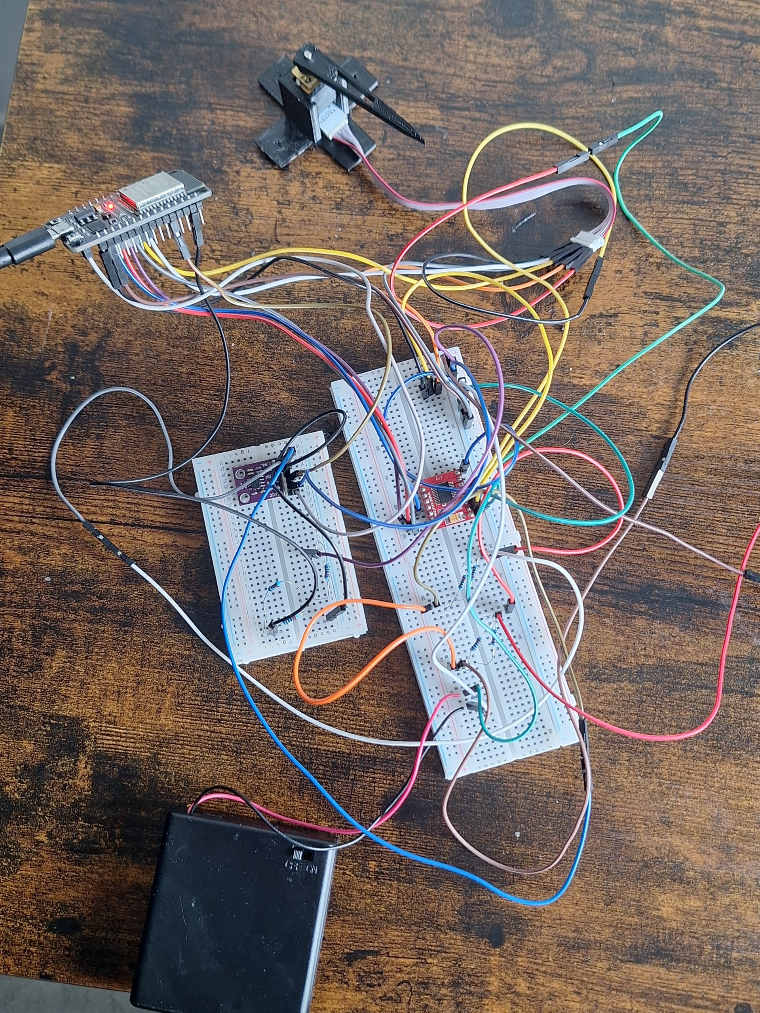
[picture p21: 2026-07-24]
media/bench_wiring.jpg

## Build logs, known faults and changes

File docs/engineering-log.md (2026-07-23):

# Engineering Log — CAN Physical-Layer Fault Isolation

*Reconstructed after the fact from session notes and serial-monitor
captures taken during bring-up. The captures below are verbatim; some were
transcribed from screenshots, so ordering within a block is faithful but
interleaving between the two nodes' monitors is approximate.*

Rough timeline: Day 1 protocol design, Day 2 PID characterisation on the
bench (direct serial, no bus), Days 3–5 CAN physical-layer bring-up — which
is what took the time and is the subject of this log.

## Summary

The CAN bus refused to pass frames for days. The root cause turned out to
be **three of five MCP2551 modules, from one hand-soldered batch, being
defective** — compounded early on by an out-of-spec 3.3 V transceiver
supply and, once, a supply wire that came loose during rewiring. What made
this tractable was not any single insight but a **diagnostic ladder**: a
sequence of tests, each of which removes one class of suspect, so that a
confusing whole-system failure is decomposed into isolated yes/no
questions.

## 1. Making failure observable

The first problem was that a dead bus is *silent*, and silence is
ambiguous: a receiver printing nothing looks identical whether the sender
is transmitting into the void or the wire is shorted. So before chasing
the fault, both nodes were instrumented with `twai_get_status_info()` —
state, TEC (transmit error counter), REC, and the bus error count printed
every 2 s — plus **bus-off auto-recovery**, because the TWAI peripheral
latches `BUS_OFF` and does not self-recover; without
`twai_initiate_recovery()` a node simply stays dead after the first error
storm.

That immediately turned silence into signal. Node B (sender) drove its
transmit error counter to the bus-off threshold after only three frames:

```
[STATUS] state=BUS_OFF  TEC=128  REC=0  tx_failed=3  bus_err=88  |  ok=3 fail=16
[STATUS] Bus-off detected -> initiating recovery...
10011ms - SEND FAILED: driver not running (bus-off/stopped - recovery will kick in)
10511ms - SEND FAILED: driver not running (bus-off/stopped - recovery will kick in)
11011ms - SEND FAILED: driver not running (bus-off/stopped - recovery will kick in)
[STATUS] state=STOPPED  TEC=0  REC=0  tx_failed=3  bus_err=88  |  ok=3 fail=20
[STATUS] Driver stopped -> restarting...
12011ms - sent OK: ID=0x001 payload=0xDEADBEEF
12511ms - SEND FAILED: driver not running (bus-off/stopped - recovery will kick in)
```

Node A (receiver) at the same moment — every counter at zero, meaning it
was not merely missing frames, it was seeing *no bus activity at all*:

```
No message received (timeout)
[STATUS] state=RUNNING  TEC=0  REC=0  tx_failed=0  rx_missed=0  arb_lost=0  bus_err=0
No message received (timeout)
[STATUS] state=RUNNING  TEC=0  REC=0  tx_failed=0  rx_missed=0  arb_lost=0  bus_err=0
```

Reading the two together: the sender is putting frames on the wire and
reading back corruption; the receiver's side of the bus is electrically
dead.

## 2. Three distinct failure modes, told apart by the counters

The instrumentation paid off by making genuinely different faults
*distinguishable*, where on a bare bus they had all looked like "nothing
works."

**Zero errors, but nothing transmits** — after moving the transceivers to
5 V (see §4), a new signature appeared:

```
[STATUS] state=RUNNING  TEC=0  REC=0  tx_failed=0  bus_err=0  |  ok=6 fail=309
157009ms - SEND TIMEOUT (bus is connected, so this is a real fault)
157509ms - SEND TIMEOUT (bus is connected, so this is a real fault)
[STATUS] state=RUNNING  TEC=0  REC=0  tx_failed=0  bus_err=0  |  ok=6 fail=313
```

All error counters at zero *with* transmits timing out means the
controller never sees the bus go idle, so it never begins arbitration —
consistent with the RX line being held dominant. Traced to a transceiver
whose supply had come loose during rewiring (VCC reading 2.2 V,
back-fed through the input protection diodes rather than actually powered).

**Traffic crossing, but corrupted** — a third signature, with `bus_err`
climbing ~5,000 every 2 s (~2,500 corrupted frames/s) and TEC pinned at
the error-passive threshold:

```
[STATUS] state=RUNNING  TEC=128  REC=0  tx_failed=0  bus_err=291643  |  ok=6 fail=225
[STATUS] state=RUNNING  TEC=128  REC=0  tx_failed=0  bus_err=296694  |  ok=6 fail=229
[STATUS] state=RUNNING  TEC=128  REC=0  tx_failed=0  bus_err=301744  |  ok=6 fail=233
```

Node A now registering receive errors where before all counters were zero
— the first hard evidence of signals actually crossing the bus:

```
[STATUS] state=RUNNING  TEC=0  REC=131  tx_failed=0  rx_missed=0  arb_lost=0  bus_err=13
```

## 3. The decisive test — per-node self-test

The breakthrough was a diagnostic that needs no working partner:
`TWAI_MODE_NO_ACK` with self-reception requested, so a node transmits
through its *own* transceiver and the *real* bus wiring and receives its
own frame back. Flash it to one node, power that node alone, and you get a
pass/fail for that node's entire physical loop
(MCU → TXD → CANH/CANL → RXD → MCU).

Node B:

```
TX: ok | RX: got own frame ID=0x055 AA 55  <- PHYSICAL LOOP OK
TX: ok | RX: got own frame ID=0x055 AA 55  <- PHYSICAL LOOP OK
TX: ok | RX: got own frame ID=0x055 AA 55  <- PHYSICAL LOOP OK
```

Node A:

```
TX: FAIL | RX: NOTHING <- physical loop broken on THIS node
TX: FAIL | RX: NOTHING <- physical loop broken on THIS node
TX: FAIL | RX: NOTHING <- physical loop broken on THIS node
```

One test, run per node, localises the fault to **Node A** and exonerates
Node B, the bus wiring, and the shared termination in a single stroke.

## 4. Narrowing further — GPIO loopback, then cross-swap

Two more rungs, each removing a suspect:

**GPIO loopback** — jumper GPIO21 straight to GPIO22, transceiver bypassed
entirely:

```
TX: ok | RX: got own frame ID=0x055 AA 55  <- PHYSICAL LOOP OK
TX: ok | RX: got own frame ID=0x055 AA 55  <- PHYSICAL LOOP OK
```

Node A's ESP32, GPIOs, TWAI driver and firmware are all healthy — the
fault is confined to the transceiver and its immediate wiring.

**Cross-swap** — move Node B's known-good transceiver into Node A's
socket. It then passed self-test, identifying the **module itself** as the
failed part. Repeating across the batch found three of five modules dead —
a hand-soldering yield problem, not a design fault.

The 3.3 V → 5 V supply migration (with 220 Ω / 440 Ω RX dividers, see
`hardware.md`) removed the out-of-spec undervoltage that had been muddying
the picture in parallel.

## 5. Working bus

Node A receiving cleanly, all counters zero:

```
Received  ID: 0x001  DLC: 4  Data: DE AD BE EF
Received  ID: 0x001  DLC: 4  Data: DE AD BE EF
Received  ID: 0x001  DLC: 4  Data: DE AD BE EF
[STATUS] state=RUNNING  TEC=0  REC=0  tx_failed=0  rx_missed=0  arb_lost=0  bus_err=0
```

Node B — note `bus_err` frozen at its pre-fix total while TEC *decays* as
successful transmissions retire accumulated error credit, the protocol's
own error counter visibly healing:

```
[STATUS] state=RUNNING  TEC=86  REC=0  tx_failed=0  bus_err=17073  |  ok=131 fail=8
70009ms - sent OK: ID=0x001 payload=0xDEADBEEF
[STATUS] state=RUNNING  TEC=82  REC=0  tx_failed=0  bus_err=17073  |  ok=135 fail=8
[STATUS] state=RUNNING  TEC=78  REC=0  tx_failed=0  bus_err=17073  |  ok=139 fail=8
[STATUS] state=RUNNING  TEC=74  REC=0  tx_failed=0  bus_err=17073  |  ok=143 fail=8
```

## Supporting measurements

| Point | Reading | Note |
|---|---|---|
| CANH–CANL, bus assembled, unpowered | ~55 Ω | two ~110 Ω terminations in parallel — correct |
| CANH–GND / CANL–GND, unpowered | high kΩ / OL | no resistive leak to ground |
| Node A transceiver VCC after 5 V migration | 5.0 V | |
| Node B transceiver VCC after 5 V migration | 4.6 V | in spec (4.5 V min) but little headroom |
| RX divider midpoint, bus idle | ~2.7–3.0 V | above the ESP32 logic-high threshold |
| Failing transceiver CRX, bus idle | 0 V | should sit high (recessive) — the failure signature |
| Failing transceiver CANH / CANL under transmit | both ~1.8 V | no differential — transmitter not driving |

Termination resistors verified as 220 Ω 1 % (red-red-black-black-brown).
Earlier in-circuit readings of ~110 Ω and ~44 Ω were measurement artifacts
of probing resistors in parallel while still on the board.

## What made the method work

Each rung of the ladder answers exactly one question and removes one class
of suspect:

1. **Status telemetry** — is the bus dead, corrupted, or idle-starved?
   (Turns silence into a signature.)
2. **Self-test (`NO_ACK` + self-reception)** — is the fault on *this* node
   or elsewhere? (No working partner required.)
3. **GPIO loopback** — is it the MCU/firmware or the analogue front end?
4. **Cross-swap** — is it the component or the wiring?

The order matters: each test is only meaningful once the ones above it
have narrowed the field. That discipline is what turned "the bus doesn't
work" into "module 3 of 5 is dead."

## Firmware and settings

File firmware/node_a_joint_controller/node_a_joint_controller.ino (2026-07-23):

/*
 * Node A - Joint controller
 *
 * Receives 0x100 position commands over CAN, runs a closed-loop PID
 * position controller against the quadrature encoder, drives the motor
 * through a TB6612 H-bridge, and publishes 0x110 status at 10 Hz.
 *
 * Bus: ESP32 TWAI, 250 kbit/s, CTX=GPIO21, CRX=GPIO22 (via RX divider).
 */

#include "driver/twai.h"

// ---- CAN ----
#define CAN_TX_PIN GPIO_NUM_21
#define CAN_RX_PIN GPIO_NUM_22
#define ID_CMD_POS   0x100
#define ID_STATUS    0x110

// ---- Motor / encoder (validated pins - DO NOT CHANGE) ----
#define AIN1 26
#define AIN2 27
#define PWMA 25
#define STBY 14
#define ENC_A 32
#define ENC_B 33

// Hand-calibrated, replacing the nominal datasheet figure.
const float COUNTS_PER_REV = 1146.0;
const float DEG_PER_COUNT  = 360.0 / COUNTS_PER_REV;

// ---- PID (empirically tuned) ----
const float Kp = 10.0, Ki = 0.1, Kd = 0.1;
const int   STICTION_PWM = 35;      // min duty that breaks static friction
const float DEADBAND_DEG = 0.6;     // prevents limit-cycling at setpoint
const float I_CLAMP      = 50.0;    // anti-windup against static friction
const float ANGLE_MIN = -45.0, ANGLE_MAX = 180.0;

volatile long encoderCount = 0;
float targetDeg = 0.0;
float integral = 0.0, lastErr = 0.0;
unsigned long lastPid = 0, lastStatus = 0;
int lastPwm = 0;

void IRAM_ATTR encoderISR() {
  if (digitalRead(ENC_B)) encoderCount--; else encoderCount++;
}

/*
 * Motor drive direction is inverted relative to the naive convention.
 * With the un-swapped logic, drive direction and encoder counting
 * direction disagree: every correction grows the error, PWM saturates
 * at 255 and the joint runs away. AIN1/AIN2 are swapped here to match
 * the encoder's counting sense.
 */
void setMotor(int pwm) {
  pwm = constrain(pwm, -255, 255);
  lastPwm = pwm;
  if (pwm > 0)      { digitalWrite(AIN1, HIGH); digitalWrite(AIN2, LOW);  }
  else if (pwm < 0) { digitalWrite(AIN1, LOW);  digitalWrite(AIN2, HIGH); }
  else              { digitalWrite(AIN1, LOW);  digitalWrite(AIN2, LOW);  }
  ledcWrite(PWMA, abs(pwm));
}

float currentDeg() { return encoderCount * DEG_PER_COUNT; }

void sendStatus() {
  twai_message_t m = {};
  m.identifier = ID_STATUS;
  m.data_length_code = 8;
  int16_t pos = (int16_t)(currentDeg() * 10);
  int16_t tgt = (int16_t)(targetDeg * 10);
  int16_t err = (int16_t)((targetDeg - currentDeg()) * 10);
  m.data[0] = pos & 0xFF; m.data[1] = pos >> 8;
  m.data[2] = tgt & 0xFF; m.data[3] = tgt >> 8;
  m.data[4] = err & 0xFF; m.data[5] = err >> 8;
  m.data[6] = (uint8_t)min(abs(lastPwm), 255);
  m.data[7] = (fabs(targetDeg - currentDeg()) <= DEADBAND_DEG) ? 1 : 0;
  twai_transmit(&m, 0);
}

void setup() {
  Serial.begin(115200);
  pinMode(AIN1, OUTPUT); pinMode(AIN2, OUTPUT); pinMode(STBY, OUTPUT);
  pinMode(ENC_A, INPUT_PULLUP); pinMode(ENC_B, INPUT_PULLUP);
  digitalWrite(STBY, HIGH);
  ledcAttach(PWMA, 20000, 8);   // ESP32 core 3.x API
  attachInterrupt(digitalPinToInterrupt(ENC_A), encoderISR, RISING);

  twai_general_config_t g =
      TWAI_GENERAL_CONFIG_DEFAULT(CAN_TX_PIN, CAN_RX_PIN, TWAI_MODE_NORMAL);
  twai_timing_config_t t = TWAI_TIMING_CONFIG_250KBITS();
  twai_filter_config_t f = TWAI_FILTER_CONFIG_ACCEPT_ALL();
  twai_driver_install(&g, &t, &f);
  twai_start();

  targetDeg = currentDeg();   // hold position on boot, no jump
  Serial.println("Node A: joint controller ready");
}

void loop() {
  twai_message_t rx;
  while (twai_receive(&rx, 0) == ESP_OK) {
    if (rx.identifier == ID_CMD_POS && rx.data_length_code >= 2) {
      int16_t raw = (int16_t)(rx.data[0] | (rx.data[1] << 8));
      targetDeg = constrain(raw / 10.0, ANGLE_MIN, ANGLE_MAX);
      Serial.printf("CMD: %.1f deg\n", targetDeg);
    }
  }

  unsigned long now = millis();

  // --- PID @ 100 Hz ---
  if (now - lastPid >= 10) {
    float dt = (now - lastPid) / 1000.0;
    lastPid = now;

    float err = targetDeg - currentDeg();
    int pwm = 0;

    if (fabs(err) > DEADBAND_DEG) {
      integral = constrain(integral + err * dt, -I_CLAMP, I_CLAMP);
      float deriv = (err - lastErr) / dt;
      pwm = (int)(Kp * err + Ki * integral + Kd * deriv);
      // friction compensation: below breakaway duty the motor does not
      // move at all, so the integral would wind up fighting stiction
      if (pwm > 0 && pwm <  STICTION_PWM) pwm =  STICTION_PWM;
      if (pwm < 0 && pwm > -STICTION_PWM) pwm = -STICTION_PWM;
    } else {
      integral = 0;
    }
    lastErr = err;
    setMotor(pwm);
  }

  // --- status @ 10 Hz ---
  if (now - lastStatus >= 100) { lastStatus = now; sendStatus(); }
}

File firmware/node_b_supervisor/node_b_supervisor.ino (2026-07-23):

/*
 * Node B - Supervisor
 *
 * Issues 0x100 position commands onto the bus and consumes the joint
 * controller's 0x110 status stream.
 *
 * Serial commands (115200 baud, Newline line ending):
 *   <number>  target angle in degrees, clamped to -45..180
 *   L         toggle CSV telemetry logging
 *
 * In logging mode every received status frame is printed as
 *   ms,pos,target,err,pwm,settled
 * so the monitor output can be pasted straight into a .csv for
 * step-response analysis.
 */

#include "driver/twai.h"

#define ID_CMD_POS 0x100
#define ID_STATUS  0x110

bool logging = false;

void setup() {
  Serial.begin(115200);
  delay(500);

  twai_general_config_t g =
      TWAI_GENERAL_CONFIG_DEFAULT(GPIO_NUM_21, GPIO_NUM_22, TWAI_MODE_NORMAL);
  twai_timing_config_t t = TWAI_TIMING_CONFIG_250KBITS();
  twai_filter_config_t f = TWAI_FILTER_CONFIG_ACCEPT_ALL();
  twai_driver_install(&g, &t, &f);
  twai_start();

  Serial.println("Supervisor. Commands: angle (-45..180) | L = toggle logging");
}

void loop() {
  if (Serial.available()) {
    char c = Serial.peek();
    if (c == 'L' || c == 'l') {
      Serial.read();
      while (Serial.available()) Serial.read();
      logging = !logging;
      if (logging) Serial.println("ms,pos,target,err,pwm,settled");
      else         Serial.println("# logging off");
    } else {
      /*
       * parseFloat() must be called exactly once and stored. Arduino's
       * constrain() is a macro that substitutes its first argument three
       * times, so constrain(Serial.parseFloat(), lo, hi) reads the serial
       * buffer up to three times: the first call consumes the number, the
       * later ones find an empty buffer, block for the 1 s parse timeout
       * and return 0 - and the macro yields that last value. Every command
       * was sent as 0.0.
       */
      float raw_cmd = Serial.parseFloat();
      while (Serial.available()) Serial.read();
      float cmd = constrain(raw_cmd, -45.0, 180.0);

      int16_t raw = (int16_t)(cmd * 10);
      twai_message_t m = {};
      m.identifier = ID_CMD_POS;
      m.data_length_code = 2;
      m.data[0] = raw & 0xFF;
      m.data[1] = raw >> 8;
      if (twai_transmit(&m, pdMS_TO_TICKS(100)) == ESP_OK)
        Serial.printf("# command sent: %.1f\n", cmd);
      else
        Serial.println("# SEND FAILED");
    }
  }

  static unsigned long lastPrint = 0;
  twai_message_t rx;
  while (twai_receive(&rx, 0) == ESP_OK) {
    if (rx.identifier != ID_STATUS || rx.data_length_code != 8) continue;

    int16_t pos = rx.data[0] | (rx.data[1] << 8);
    int16_t tgt = rx.data[2] | (rx.data[3] << 8);
    int16_t err = rx.data[4] | (rx.data[5] << 8);

    if (logging) {
      Serial.printf("%lu,%.1f,%.1f,%.1f,%u,%u\n",
                    millis(), pos/10.0, tgt/10.0, err/10.0,
                    rx.data[6], rx.data[7] & 1);
    } else if (millis() - lastPrint > 500) {
      lastPrint = millis();
      Serial.printf("STATUS: pos=%.1f  target=%.1f  err=%.1f  pwm=%u  %s\n",
                    pos/10.0, tgt/10.0, err/10.0, rx.data[6],
                    rx.data[7] & 1 ? "[SETTLED]" : "");
    }
  }
}

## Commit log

2026-06-26 pushed demo results
    [mock_trial.csv]
2026-06-26 uploaded PID tuning results, step response CSV, tracking plots
    [day2_step_response.csv]
2026-06-26 Node b sketch, motor bracken CAD
    [motor_bracket.scad]
2026-06-27 Node B CAN working sketch with TWAI driver installed inside
    [motor_bracket.scad, motor_bracket.stl, motor_bracket_body.scad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]
2026-07-23 chore: add .gitignore and repository structure
    Establish firmware/ docs/ cad/ analysis/ media/ tree. Ignore Arduino build output, __pycache__, slicer .gcode, and OS cruft. Remove committed .DS_Store files.
2026-07-23 refactor: move PID position controller into firmware/
    Relocate the joint-controller sketch into firmware/node_a_joint_controller/ (Arduino folder/sketch names matched). No code changes.
2026-07-23 analysis: day 2 step response data and tracking plots
    Move real Day 2 step-response CSV into analysis/data/ and the commanded-vs-actual and tracking-error plots into analysis/figures/. Update analyze_step_response.py to read from data/ and write figures to figures/.
    [day2_step_response.csv]
2026-07-23 feat(firmware): basic TWAI send/receive bring-up sketches
    Minimal CAN bring-up: Node B transmits a fixed 0xDEADBEEF frame, Node A listens and prints any frame received. No diagnostics yet - these are the sketches from before the bus was found to be failing silently. Node A receiver reconstructed from session notes (original lost to sketch-file reuse); header documents this.
    [node_a_can_test.ino, node_b_can_test.ino]
2026-07-23 docs: hardware wiring, pin assignments, bus termination
    Document the bring-up hardware: CAN CTX/CRX on GPIO21/22 (transceivers at 3.3V, no RX divider, level shifters skipped as defective), TB6612 motor pins, quadrature encoder, and 110-ohm-per-node termination (~55 ohm across the bus). Flags the MCP2551 3.3V undervoltage as a known risk. CPR left at 700 nominal pending physical calibration.
2026-07-23 feat(firmware): TWAI status telemetry and bus-off auto-recovery
    A silent bus looks identical whether nothing transmits or every frame is corrupted. Instrument both nodes with twai_get_status_info() - state, TEC, REC, tx_failed, bus_err printed every 2s - so failure modes become distinguishable. Add bus-off auto-recovery: TWAI latches BUS_OFF and does not self-recover, so without twai_initiate_recovery() a node stays dead until manual reset. Node B now treats the bus as connected (a send timeout is a real fault, not 'normal').
    [node_a_can_test.ino, node_b_can_test.ino]
2026-07-23 feat(firmware): add self-test physical-layer diagnostic tool
    Node-agnostic per-node pass/fail for the whole physical loop (MCU -> transceiver TXD -> CANH/CANL -> transceiver RXD -> MCU) using TWAI_MODE_NO_ACK with self-reception, so a node tests itself through its real transceiver and bus wiring without needing a working partner. Flash to one node, power it alone: 'PHYSICAL LOOP OK' vs 'RX: NOTHING' localises a fault to a single node.
    [self_test.ino]
2026-07-23 fix(hardware): run transceivers at 5V with RX dividers
    The MCP2551 is spec'd for 4.5-5.5V; running it at 3.3V was out of spec and a suspected source of silent frame loss during bring-up. Move transceiver VCC to 5V and add a 220/440 ohm divider on each RX line to bring the now-5V RXD back down to ~3.3V at the ESP32. TXD stays direct (3.3V is a valid logic high in). Measured 5.0V/4.6V rails, ~2.7-3.0V divider midpoints - in spec but thin; a 3.3V-native transceiver would remove the dividers entirely.
2026-07-23 docs: engineering log - CAN physical-layer fault isolation
    Write up the diagnostic ladder that localised days of CAN bring-up failure to three defective MCP2551 modules in a hand-soldered batch: status telemetry to make silence legible, TWAI_MODE_NO_ACK self-test for per-node pass/fail without a partner, GPIO loopback to separate MCU from front end, and cross-swap to separate component from wiring. Includes verbatim serial captures and supporting bench measurements. Reconstructed from session notes.
2026-07-23 feat(firmware): joint controller - CAN position command driving PID loop
    Node A receives 0x100 position commands over CAN, runs a 100 Hz closed-loop PID (Kp=10, Ki=0.1, Kd=0.1) against the quadrature encoder with stiction breakaway (35 PWM), 0.6 deg deadband and integral anti-windup clamp, drives the TB6612, and publishes 0x110 status at 10 Hz. Encoder hand-calibrated at 1146 counts/rev. Replaces the Day-1 bench sketch.
    [node_a_joint_controller.ino]
2026-07-23 feat(firmware): supervisor node - command entry and status display
    Node B issues 0x100 position commands from typed serial input (clamped -45..180) and consumes the 0x110 status stream, printing a throttled human-readable STATUS line with a [SETTLED] flag. Command entry and monitoring only; CSV telemetry logging comes next.
    [node_b_supervisor.ino]
2026-07-23 fix(firmware): correct motor direction to match encoder count direction
    First battery-powered run commanding 90 deg ran away instead of settling: drive direction opposed the encoder's counting sense, so each correction grew the error - positive feedback - and PWM saturated at 255:
    STATUS: pos=369.3 target=90.0 err=-279.3 pwm=255
    STATUS: pos=-968.3 target=90.0 err=1058.3 pwm=255
    STATUS: pos=-2642.4 target=90.0 err=2732.4 pwm=255
    Swap the AIN1/AIN2 logic in setMotor() so drive direction agrees with the encoder, turning positive feedback back into negative. This is one of exactly two valid fixes (the other is flipping the encoder ISR sign).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
    [node_a_joint_controller.ino]
2026-07-23 feat(firmware): CSV telemetry logging mode in supervisor
    Add an 'L' serial toggle that switches the supervisor from human-readable STATUS lines to CSV: every 0x110 status frame prints as ms,pos,target,err,pwm,settled, so the monitor output pastes straight 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
2026-07-23 fix(firmware): read serial command once before constraining
    constrain() is a macro that substitutes its first argument three times, so constrain(Serial.parseFloat(), -45, 180) read the serial buffer up to three times per command: the first call consumed the number, the later ones hit an empty buffer, blocked for the 1 s parse timeout and returned 0 - and the macro yields that last evaluation, so every command was transmitted as 0.0. Read parseFloat() once into a variable, then constrain the stored value.
    [node_b_supervisor.ino]
2026-07-23 analysis: step response characterisation over CAN
    Characterise closed-loop step response driven over the bus across -45 to 180 deg, from serial captures of the 10 Hz status stream (the high-rate CSV path was dropped as not worth the bench time; transient peaks between 500 ms display prints are therefore unresolved, and provenance/caveats are stated in the doc). Steady-state error 0.0-0.5 deg, bounded by the 0.6 deg deadband by design. Large fast moves overshoot and are walked back at the pwm=35 stiction floor - attributed to printed-lever inertia back-driving the joint while the TB6612 coasts (both inputs LOW) rather than brakes; 'brake on stop' noted for the roadmap.
2026-07-24 feat(cad): OpenSCAD N20 mount and lever (original design)
    Original OpenSCAD generators and their STLs, moved out of docs/ into cad/. First mount design: printed, but could not be assembled - a cylindrical closed pocket, and the encoder PCB and JST connector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
    [motor_bracket.stl, motor_bracket_body.scad, motor_bracket_body.stl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]
2026-07-24 feat(cad): parametric N20 mount generator in Python/trimesh (test-fit)
    First parametric generator - the design moves from OpenSCAD to Python/trimesh here, once fit dimensions started needing rapid iteration (named-constant block at top, regenerates its STL). Rectangular open-top channel instead of the closed bore. Printed as a test-fit, but the shaft sits horizontal, which swings the lever in the vertical plane - gravity then loads the joint as a function of angle and invalidates the horizontal-plane PID tuning. Orientation fixed next.
    [n20_mount_test_fit.stl]
2026-07-24 fix(cad): vertical shaft-up orientation - mount used for the working demo
    Rotate to a vertical shaft-up U-tower so the lever swings in the horizontal plane and gravity no longer loads the joint by angle, matching the validated PID tuning. Front open full height; the encoder PCB, connector and disc hang in free air, untouched. This is the mount printed and used for the working demo. Known weakness: only three faces (spine + two sides) grip the motor can, so reaction torque can rock it - addressed in later revisions.
    [n20_vertical_mount.stl]
2026-07-24 feat(cad): rev3 closed-grip mount + D-bore lever (rejected in review, never printed)
    rev3 closes the grip band into a four-sided tube (adds a front wall) for rigidity against reaction torque, puts the mount on a plus-shaped base, and introduces a lever with a D-shaped bore keyed to the motor's D-shaft to stop the round bore slipping out of encoder registration. Caught in review before any print: the motor drops in from the top, so a closed grip-band tube repeats the original failure - the wide encoder end can't pass down through it. Never fabricated; the defect was found by inspection. The D-bore lever is likewise designed-but-unprinted - the motor still runs the original round-bore lever, s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
    [lever_arm.stl, n20_mount_rev3.stl]
2026-07-24 feat(cad): rev4 open-front mount with slide-in retaining plate
    Resolve the insertion problem: keep the front open full height so the encoder end drops straight in, then close the grip band afterwards with a separate front plate that slides into grooves in the side walls. Assemblable - unlike the original and rev3 closed pockets.
    [n20_front_plate.stl, n20_mount_rev4.stl]
2026-07-24 feat(cad): rev4-lite - reduced base to cut print time (current mount)
    Same open-front + slide-in-plate design as rev4, with the base span reduced 72->58 mm and thickness 3.5->2.6 mm to cut print time. Printed and currently in use.
    [n20_front_plate_lite.stl, n20_mount_rev4_lite.stl]
2026-07-24 feat(cad): D-shaft fit-test coupon (tooling, not printed)
    Generator for D-bore fit-test coupons to size the lever coupling against the motor's D-shaft. Not printed - an ~18 min print wasn't justified, so the lever bore was instead set to a mid-value of 2.40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
    [d_shaft_fit_coupon.stl, d_shaft_fit_coupon_small.stl]
2026-07-24 docs: align protocol spec with the int16 fixed-point implementation
    protocol.md still described the abandoned Day-1 float format; the firmware sends int16 in 0.1 deg units. Rewrite 0x100/0x110 to match what actually ships (2-byte command; 8-byte status of pos/target/err int16 + effort uint8 + settled flag), fix the encode/decode example, and correct the stale 'MCP2551 at 3.3V' debug note to the 5V + divider design.
2026-07-24 docs: README with architecture, results, and known limitations
    Full rewrite. The old README claimed a float protocol, a <=0.3 deg figure from a single observation, a 2S-LiPo supply, and a repo layout that no longer exists. New README documents the system as built: architecture diagram, accurate int16 protocol, 5V physical layer, PID control, step-response results (0.0-0.5 deg bounded by the 0.6 deg deadband), the CAN fault-isolation engineering log, the CAD iteration, an honest known-limitations section, and an authors/attribution split. Embeds the Day-2 tuning figures (labelled as pre-CAN direct serial).
2026-07-24 fix(analysis): point live logger at the supervisor CSV schema
    logger_plotter.py's live serial path still expected the Day-1 3-field format (t_ms,setpoint_deg,actual_deg) and silently dropped every line of the supervisor's actual ms,pos,target,err,pwm,settled output. Parse the 6-field schema (map pos->actual, target->setpoint, err->error) and mark the script's provenance as Day-1/2 bench tooling, pointing at analysis/step_response_over_can.md for the real CAN capture.
    [logger_plotter.py]
2026-07-24 docs: record hand-calibrated 1146 counts/rev (physical accuracy unverified)
    The firmware uses 1146 counts/rev (the nominal 700 was wrong on this unit). It was derived from encoder counts, not checked against an independent physical angle measurement, so absolute angular accuracy is unconfirmed - stated as such here and in the README limitations.
2026-07-24 fix(cad): oversize lever bore for PETG shrinkage
    The rev3 D-bore lever (3.10 mm bore / 2.40 across-flat / 7 mm hub) bound halfway onto the shaft - PETG bores print ~0.1-0.3 mm undersized, so a 3.10 nominal hole was an interference fit on the 3.0 mm shaft. This version opens the bore to 3.40 mm / 2.60 across-flat, shortens the hub to 5.5 mm, and adds a lightening slot at 3.5 mm thickness (1753 -> 1237 mm3). Printed and fitted to the motor - the D-bore lever is now the part in use. (Generator lever_arm_demo_v2.py to follow.)
    [lever_arm_demo_v2.stl]
2026-07-24 docs: add demo video and wiring photographs
    Demo video (0->45->90->0->-45 step sequence) and bench photos: joint assembly close-up, Node B transceiver + RX divider, and two full-bench overheads. Video is the 5.9 MB re-encode; the 175 MB origin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
2026-07-24 docs: finalise README results/limitations/authors and embed wiring photo
    README: headline restated as 0.0-0.5 deg across -45..180 within the 0.6 deg deadband (a design tradeoff, not a ceiling); add mount lead image and demo-video link; three known limitations (encoder scaling unverified, fast-step overshoot with the coast-vs-brake cause, telemetry lastPwm sampling artifact); D-bore lever noted as printed and fitted; authors split by contribution. hardware.md: embed the Node B transceiver + RX-divider photo.
2026-07-24 feat(cad): add lever_arm_demo_v2 generator
    Parametric trimesh generator for the printed D-bore lever committed earlier: bore 3.40/2.60 mm (oversized for PETG shrinkage), 5.5 mm hub, 3.5 mm arm with a tapered lightening slot (1753 -> 1237 mm3)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
